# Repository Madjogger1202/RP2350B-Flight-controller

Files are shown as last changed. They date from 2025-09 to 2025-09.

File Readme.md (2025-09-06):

# RP2350B-Flight-controller  

> Ultra-compact flight controller for mini quadcopters, based on **RP2350B** MCU.  
> Board size: **30.5 × 39.8 mm**, yet includes IMU, radio module, motor drivers, and full USB power support.  
 
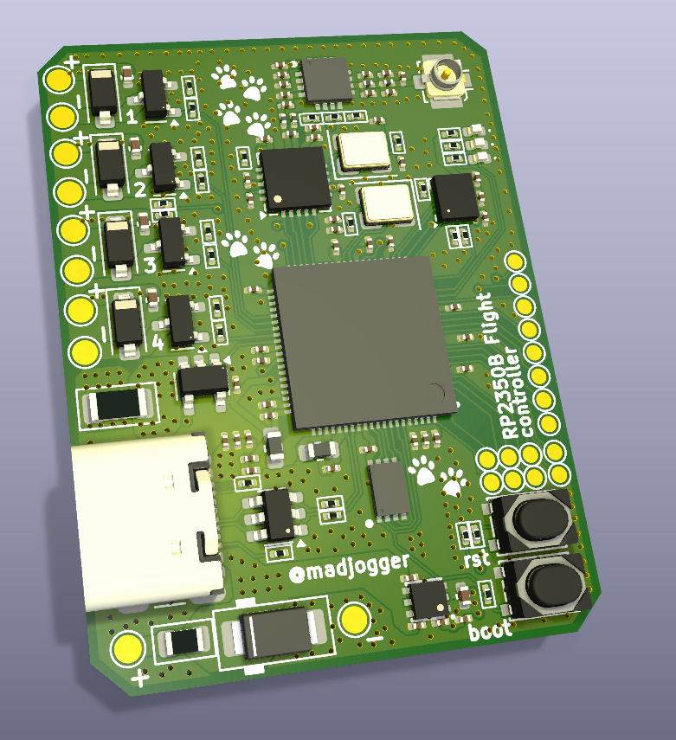
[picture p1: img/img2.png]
  

---

## Key Features  
- **MCU:** RP2350B (dual-core, PIO, USB device)  
- **IMU:** LSM6DS3 (accelerometer + gyroscope, SPI connection)  
- **Radio module:** NRF24L01 + RFX2401C PA/LNA amplifier  
- **Motors:** 4× brushed DC motors (up to 5 A per channel, short peak)  
- **USB-powered flight possible** (low-current motors, enough supply over USB)  
- **Additional expansion pins** (GPIO3–16 + SWD) for sensors, debugging, or add-ons  

---

## Pin Mapping  

### IMU (LSM6DS3) — SPI2  
| RP2350B GPIO | Signal | Notes |
|---|---|---|
| GPIO19 | SPI2_MISO | Sensor data out |
| GPIO22 | SPI2_MOSI | Sensor data in |
| GPIO23 | SPI2_SCK  | SPI clock |
| GPIO20 | IMU_INT1  | Interrupt 1 |
| GPIO21 | IMU_INT2  | Interrupt 2 |

---

### Radio Module (NRF24L01 + RFX2401C)  
| RP2350B GPIO | Signal | Notes |
|---|---|---|
| GPIO28 | SPI_MOSI | Shared SPI bus |
| GPIO36 | SPI_MISO | Shared SPI bus |
| GPIO37 | SPI_SCK  | Shared SPI bus |
| GPIO30 | NRF_CS | Chip select |
| GPIO31 | NRF_CE | Enable |
| GPIO32 | NRF_IRQ  | Interrupt |

---

### Motors  
| RP2350B GPIO | Output | Notes |
|---|---|---|
| GPIO45 | Motor_1 | Brushed motor driver |
| GPIO46 | Motor_2 | Brushed motor driver |
| GPIO47 | Motor_3 | Brushed motor driver |
| GPIO48 | Motor_4 | Brushed motor driver |
| GPIO49 | Motor_current | Current sense |
| GPIO52 | Motor_voltage | Battery/rail voltage sense |

---

### LEDs  
| RP2350B GPIO | Signal | Notes |
|---|---|---|
| GPIO17 | LED1 | Status LED |
| GPIO18 | LED2 | Status LED |

---

### Debug / Expansion  
- **SWD interface** exposed for programming/debugging  
- **GPIO3–16** free for custom extensions (I²C, UART, SPI, PWM, ADC etc.)  

---

## Power  
- Powered from **USB** or external battery  
- USB can sustain hover/low-thrust operation with small coreless motors  
- Onboard regulation for MCU, IMU, radio, and motor supply  

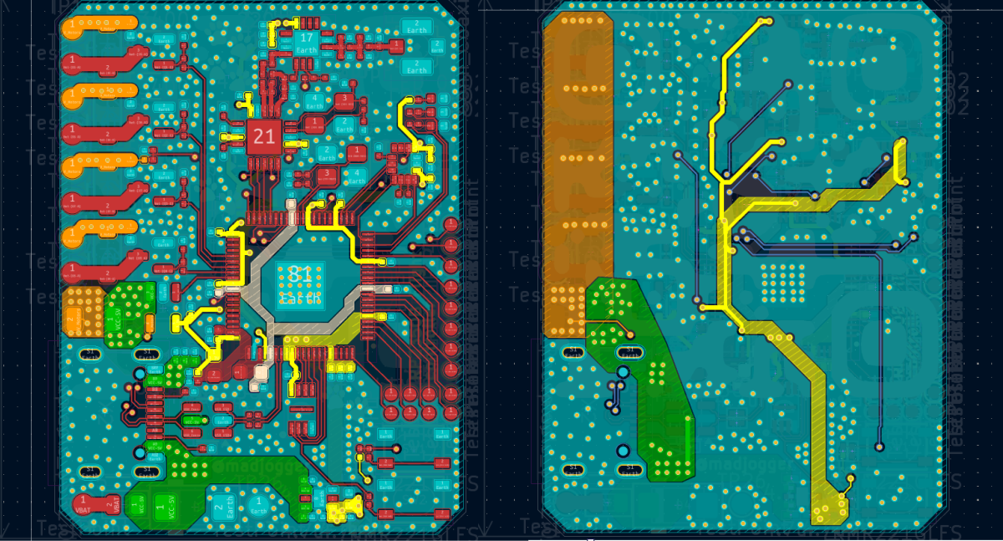
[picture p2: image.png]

---

## Use Case  
- Designed for **tiny brushed quadcopters** and robotics experiments  
- Combines **motion sensing, wireless control, and motor drivers** in one small board  
- Fits into custom drone frames without extra breakout boards  

---

## Quick Start  
1. Connect via **USB-C** for firmware flashing and testing.  
2. Flash firmware (e.g. custom flight stack on RP2350B).  
3. Connect brushed motors to outputs GPIO45–48.  
4. Pair radio link via NRF24L01 (with RFX2401C amp).  
5. Power from USB for tests, or from LiPo for flight.  

---

## Notes  
- Motor channels rated for **5 A peak per motor** (coreless brushed).  
- Ensure airflow for heat dissipation at higher loads.  
- Expansion pins allow integration of GPS, barometer, or additional sensors.  

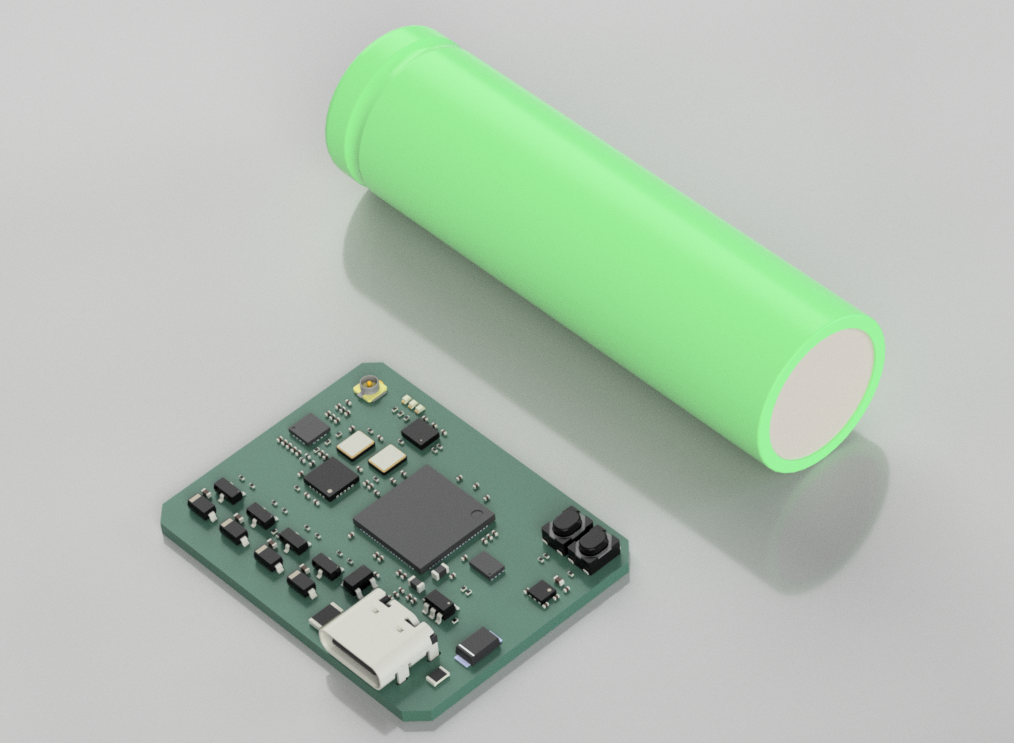
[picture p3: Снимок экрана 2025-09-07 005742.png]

---

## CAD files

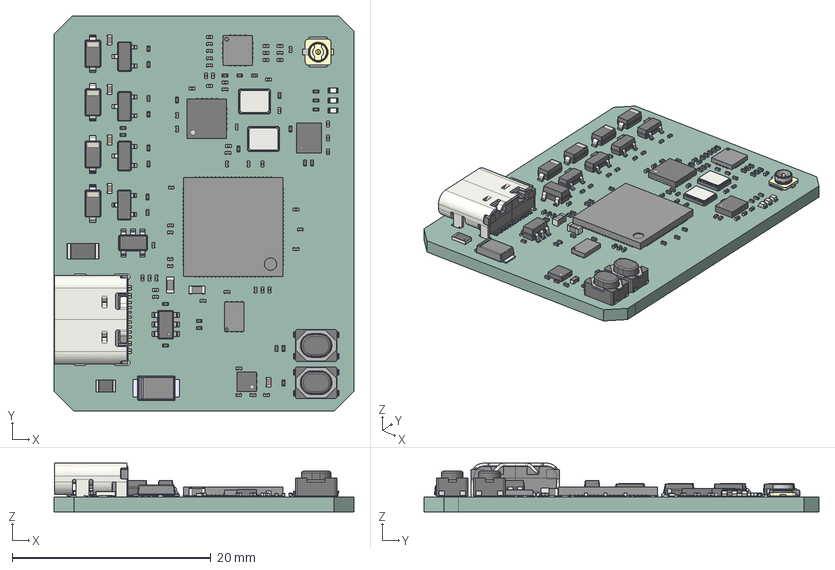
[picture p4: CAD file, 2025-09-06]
RP2350B-Flight-controller.step
30.2 x 39.8 x 4.91 mm
R_0201_0603Metric x 29
C_0201_0603Metric x 49
SS54FSH
LED_0402_1005Metric x 3
ThermalPin x 3
PinsArrayLR x 3
D_SOD-123 x 4
L_0201_0603Metric x 5
SOT-23 x 4
L_0603_1608Metric x 2
USB_C_Receptacle_GCT_USB4105-xx-A_16P_TopMnt_Horizontal
SW_SPST_PTS810 x 2
C_0402_1005Metric x 5
PinsArrayTB x 2
U.FL-R-SMT-1(80)--3DModel-STEP-1
SOT-23-5
Crystal_SMD_3225-4Pin_3.2x2.5mm x 2
QFN-20-1EP_4x4mm_P0.5mm_EP2.5x2.5mm
SOT-23-6
R_0805_2012Metric
R_1206_3216Metric
LGA-14_3x2.5mm_P0.5mm_LayoutBorder3x4y
DFN-6-1EP_2x2mm_P0.65mm_EP1x1.6mm
RP2350B-Flight-controller_PCB

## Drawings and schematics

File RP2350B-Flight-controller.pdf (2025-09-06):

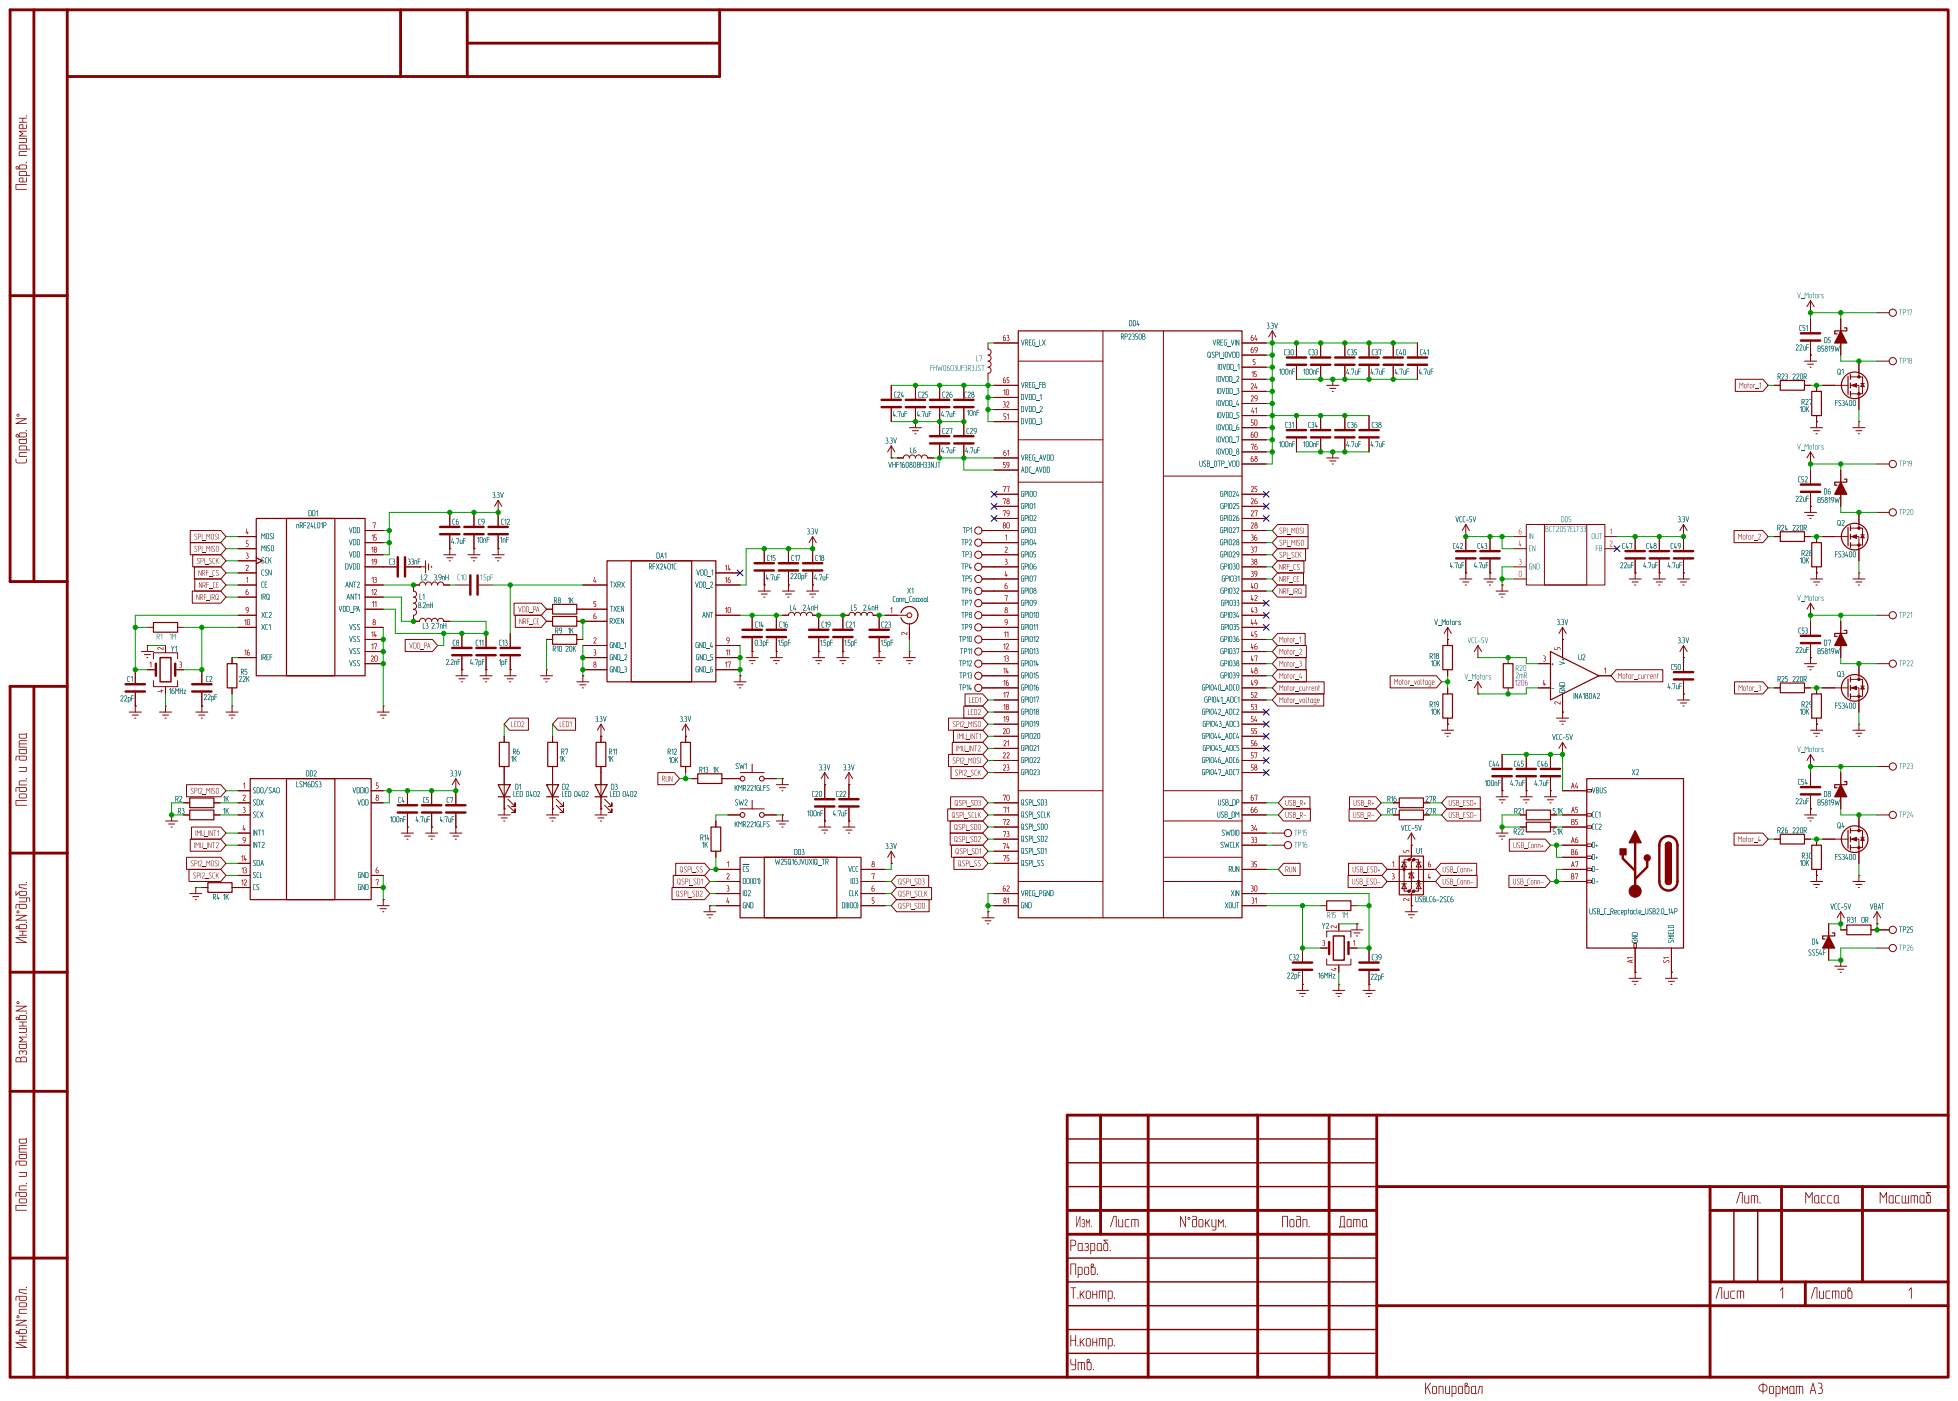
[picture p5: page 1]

þÿ@>2.
þÿ".:>=B@.

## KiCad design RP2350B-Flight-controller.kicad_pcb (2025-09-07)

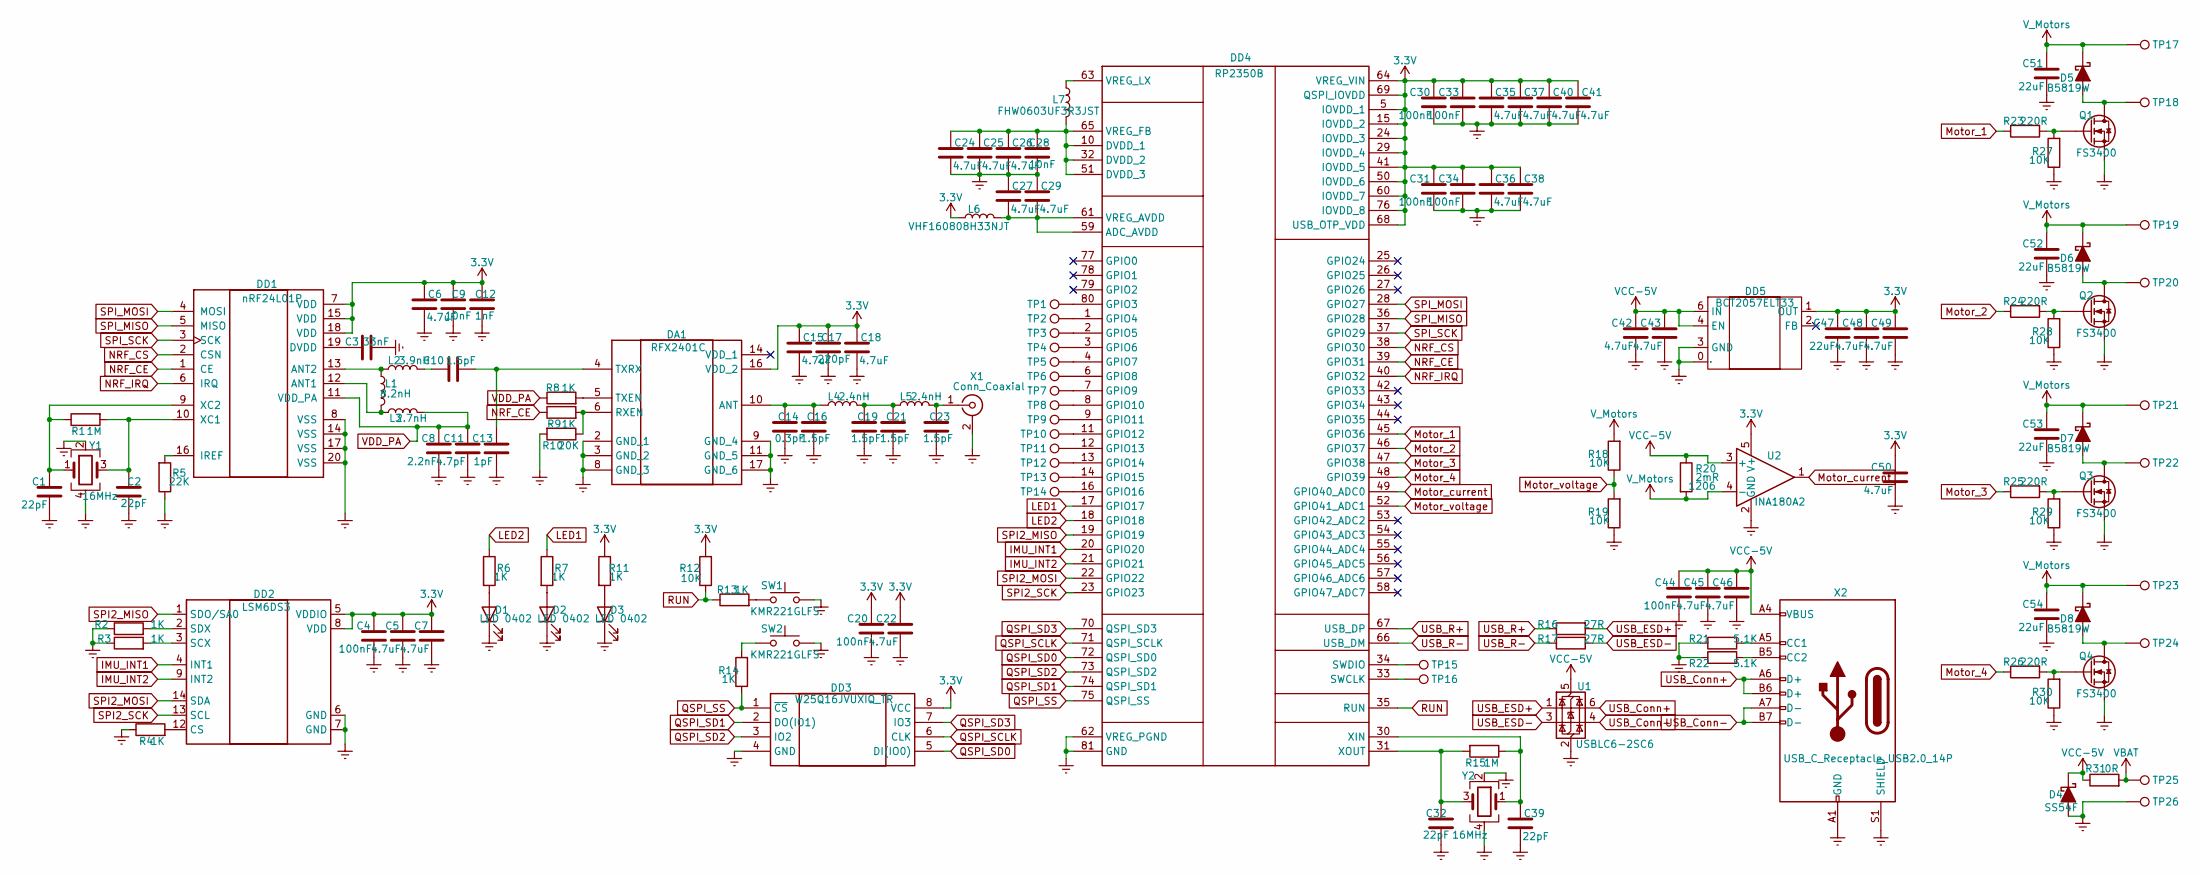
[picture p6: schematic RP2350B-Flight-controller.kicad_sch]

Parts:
C1, C2, C32, C39: 22pF; C_0201_0603Metric
C3: 33nF; C_0201_0603Metric
C4, C20, C30, C31, C33, C34, C44: 100nF; C_0201_0603Metric
C5, C6, C7, C15, C18, C22, C24, C25, C26, C27, C29, C35, C36, C37, C38, C40, C41, C42, C43, C45, C46, C48, C49, C50: 4.7uF; C_0201_0603Metric
C8: 2.2nF; C_0201_0603Metric
C9, C28: 10nF; C_0201_0603Metric
C10, C16, C19, C21, C23: 1.5pF; C_0201_0603Metric
C11: 4.7pF; C_0201_0603Metric
C12: 1nF; C_0201_0603Metric
C13: 1pF; C_0201_0603Metric
C14: 0.3pF; C_0201_0603Metric
C17: 220pF; C_0201_0603Metric
C47, C51, C52, C53, C54: 22uF; C_0402_1005Metric
D1, D2, D3: LED 0402; LED_0402_1005Metric
D4: SS54F; D_SMAFL
D5, D6, D7, D8: B5819W; D_SOD-123
DA1: RFX2401C; Manufacturer_Part_Number RFX2401C; Mouser Part Number 477-RFX2401C
DD1: nRF24L01P; QFN-20-1EP_4x4mm_P0.5mm_EP2.5x2.5mm
DD2: LSM6DS3; LGA-14_3x2.5mm_P0.5mm_LayoutBorder3x4y
DD3: W25Q16JVUXIQ_TR; W25Q16JVUXIQ; Manufacturer_Part_Number W25Q16JVUXIQ TR; Mouser Part Number 454-W25Q16JVUXIQTR
DD4: RP2350B; QFN40P1000X1000X90-81N-D; Manufacturer_Part_Number RP2350B
DD5: BCT2057ELT33; BCT2057ELTAJ; Manufacturer Part BCT2057ELTAJ-TR; LCSC Part Name 1A, 低 dropout 线性稳压器
L1: 8.2nH; L_0201_0603Metric
L2: 3.9nH; L_0201_0603Metric
L3: 2.7nH; L_0201_0603Metric
L4, L5: 2.4nH; L_0201_0603Metric
L6: VHF160808H33NJT; L_0603_1608Metric
L7: FHW0603UF3R3JST; L_0603_1608Metric
Q1, Q2, Q3, Q4: FS3400; SOT-23
R1, R15: 1M; R_0201_0603Metric
R2, R3, R4, R6, R7, R8, R9, R11, R13, R14: 1K; R_0201_0603Metric
R5: 22K; R_0201_0603Metric
R10: 20K; R_0201_0603Metric
R12, R18, R19, R27, R28, R29, R30: 10K; R_0201_0603Metric
R16, R17: 27R; R_0201_0603Metric
R20: 2mR; R_1206_3216Metric
R21, R22: 5.1K; R_0201_0603Metric
R23, R24, R25, R26: 220R; R_0201_0603Metric
R31: 0R; R_0805_2012Metric
SW1, SW2: KMR221GLFS; SW_SPST_PTS810
TP1, TP2, TP3, TP4, TP5, TP6, TP7, TP8, TP9, TP10, TP11, TP12, TP13, TP14, TP15, TP16: TestPoint; TestPoint_Pad_D1.0mm
TP17, TP18, TP19, TP20, TP21, TP22, TP23, TP24, TP25, TP26: TestPoint; TestPoint_Pad_D1.5mm
U1: USBLC6-2SC6; SOT-23-6
U2: INA180A2; SOT-23-5
X1: Conn_Coaxial; U.FL_Molex_MCRF_73412-0110_Vertical
X2: USB_C_Receptacle_USB2.0_14P; USB_C_Receptacle_GCT_USB4105-xx-A_16P_TopMnt_Horizontal
Y1, Y2: 16MHz; Crystal_SMD_3225-4Pin_3.2x2.5mm

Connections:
3.3V: C4.1, C5.1, C6.1, C7.1, C9.1, C12.1, C15.1, C17.1, C18.1, C20.1, C22.1, C30.1, C31.1, C33.1, C34.1, C35.1, C36.1, C37.1, C38.1, C40.1, C41.1, C47.1, C48.1, C49.1, C50.1, DA1.16 (VDD_2), DD1.7 (VDD), DD1.15 (VDD), DD1.18 (VDD), DD2.5 (VDDIO), DD2.8 (VDD), DD3.8 (VCC), DD4.5 (IOVDD_1), DD4.15 (IOVDD_2), DD4.24 (IOVDD_3), DD4.29 (IOVDD_4), DD4.41 (IOVDD_5), DD4.50 (IOVDD_6), DD4.60 (IOVDD_7), DD4.64 (VREG_VIN), DD4.68 (USB_OTP_VDD), DD4.69 (QSPI_IOVDD), DD4.76 (IOVDD_8), DD5.1 (OUT), L6.1, R11.1, R12.2, U2.5 (V+)
Earth: C1.2, C2.2, C3.2, C4.2, C5.2, C6.2, C7.2, C8.2, C9.2, C11.2, C12.2, C13.2, C14.2, C15.2, C16.2, C17.2, C18.2, C19.2, C20.2, C21.2, C22.2, C23.2, C24.2, C25.2, C26.2, C27.1, C28.2, C29.1, C30.2, C31.2, C32.2, C33.2, C34.2, C35.2, C36.2, C37.2, C38.2, C39.2, C40.2, C41.2, C42.2, C43.2, C44.2, C45.2, C46.2, C47.2, C48.2, C49.2, C50.2, C51.2, C52.2, C53.2, C54.2, D1.1 (K), D2.1 (K), D3.1 (K), D4.2 (A), DA1.2 (GND_1), DA1.3 (GND_2), DA1.8 (GND_3), DA1.9 (GND_4), DA1.11 (GND_5), DA1.17 (GND_6), DD1.8 (VSS), DD1.14 (VSS), DD1.17 (VSS), DD1.20 (VSS), DD1.21 (PAD), DD2.6 (GND), DD2.7 (GND), DD3.4 (GND), DD4.62 (VREG_PGND), DD4.81 (GND), DD5.0 (EP), DD5.3 (GND), Q1.2 (S), Q2.2 (S), Q3.2 (S), Q4.2 (S), R2.1, R3.1, R4.1, R5.1, R10.2, R19.1, R21.1, R22.1, R27.1, R28.1, R29.1, R30.1, SW1.1, SW2.1, TP26.1, U1.2 (GND), U2.2 (GND), X1.2 (Ext), X2.A1 (GND), X2.A12 (GND), X2.B1 (GND), X2.B12 (GND), X2.S1 (SHIELD), Y1.2, Y1.4, Y2.2, Y2.4
IMU_INT1: DD2.4 (INT1), DD4.20 (GPIO20)
IMU_INT2: DD2.9 (INT2), DD4.21 (GPIO21)
LED1: DD4.17 (GPIO17), R7.1
LED2: DD4.18 (GPIO18), R6.1
Motor_1: DD4.45 (GPIO36), R23.1
Motor_2: DD4.46 (GPIO37), R24.1
Motor_3: DD4.47 (GPIO38), R25.1
Motor_4: DD4.48 (GPIO39), R26.1
Motor_current: DD4.49 (GPIO40_ADC0), U2.1
Motor_voltage: DD4.52 (GPIO41_ADC1), R18.1, R19.2
NRF_CE: DD1.1 (CE), DD4.39 (GPIO31), R9.1
NRF_CS: DD1.2 (CSN), DD4.38 (GPIO30)
NRF_IRQ: DD1.6 (IRQ), DD4.40 (GPIO32)
unnamed: C10.1, L2.2
unnamed: C19.1, C21.1, L4.2, L5.1
unnamed: D1.2 (A), R6.2
unnamed: D2.2 (A), R7.2
unnamed: D3.2 (A), R11.2
unnamed: D5.2 (A), Q1.3 (D), TP18.1
unnamed: D6.2 (A), Q2.3 (D), TP20.1
unnamed: D7.2 (A), Q3.3 (D), TP22.1
unnamed: D8.2 (A), Q4.3 (D), TP24.1
unnamed: C14.1, C16.1, DA1.10 (ANT), L4.1
unnamed: DA1.6 (RXEN), R9.2, R10.1
unnamed: DA1.5 (TXEN), R8.2
unnamed: C10.2, C13.1, DA1.4 (TXRX)
unnamed: DD1.12 (ANT1), L1.2, L3.1
unnamed: DD1.13 (ANT2), L1.1, L2.1
unnamed: C3.1, DD1.19 (DVDD)
unnamed: DD1.16 (IREF), R5.2
unnamed: C2.1, DD1.10 (XC1), R1.2, Y1.3
unnamed: C1.1, DD1.9 (XC2), R1.1, Y1.1
unnamed: DD2.12 (CS), R4.2
unnamed: DD2.3 (SCX), R3.2
unnamed: DD2.2 (SDX), R2.2
unnamed: C27.2, C29.2, DD4.59 (ADC_AVDD), DD4.61 (VREG_AVDD), L6.2
unnamed: C24.1, C25.1, C26.1, C28.1, DD4.10 (DVDD_1), DD4.32 (DVDD_2), DD4.51 (DVDD_3), DD4.65 (VREG_FB), L7.2
unnamed: DD4.80 (GPIO3), TP1.1
unnamed: DD4.1 (GPIO4), TP2.1
unnamed: DD4.2 (GPIO5), TP3.1
unnamed: DD4.3 (GPIO6), TP4.1
unnamed: DD4.4 (GPIO7), TP5.1
unnamed: DD4.6 (GPIO8), TP6.1
unnamed: DD4.7 (GPIO9), TP7.1
unnamed: DD4.8 (GPIO10), TP8.1
unnamed: DD4.9 (GPIO11), TP9.1
unnamed: DD4.11 (GPIO12), TP10.1
unnamed: DD4.12 (GPIO13), TP11.1
unnamed: DD4.13 (GPIO14), TP12.1
unnamed: DD4.14 (GPIO15), TP13.1
unnamed: DD4.16 (GPIO16), TP14.1
unnamed: DD4.33 (SWCLK), TP16.1
unnamed: DD4.34 (SWDIO), TP15.1
unnamed: DD4.63 (VREG_LX), L7.1
unnamed: C39.1, DD4.30 (XIN), R15.1, Y2.1
unnamed: C32.1, DD4.31 (XOUT), R15.2, Y2.3
unnamed: Q1.1 (G), R23.2, R27.2
unnamed: Q2.1 (G), R24.2, R28.2
unnamed: Q3.1 (G), R25.2, R29.2
unnamed: Q4.1 (G), R26.2, R30.2
unnamed: R13.2, SW1.2
unnamed: R14.2, SW2.2
unnamed: C23.1, L5.2, X1.1 (In)
unnamed: R21.2, X2.A5 (CC1)
unnamed: R22.2, X2.B5 (CC2)
QSPI_SCLK: DD3.6 (CLK), DD4.71 (QSPI_SCLK)
QSPI_SD0: DD3.5 (DI(IO0)), DD4.72 (QSPI_SD0)
QSPI_SD1: DD3.2 (DO(IO1)), DD4.74 (QSPI_SD1)
QSPI_SD2: DD3.3 (IO2), DD4.73 (QSPI_SD2)
QSPI_SD3: DD3.7 (IO3), DD4.70 (QSPI_SD3)
QSPI_SS: DD3.1 (~CS), DD4.75 (QSPI_SS), R14.1
RUN: DD4.35 (RUN), R12.1, R13.1
SPI2_MISO: DD2.1 (SDO/SA0), DD4.19 (GPIO19)
SPI2_MOSI: DD2.14 (SDA), DD4.22 (GPIO22)
SPI2_SCK: DD2.13 (SCL), DD4.23 (GPIO23)
SPI_MISO: DD1.5 (MISO), DD4.36 (GPIO28)
SPI_MOSI: DD1.4 (MOSI), DD4.28 (GPIO27)
SPI_SCK: DD1.3 (SCK), DD4.37 (GPIO29)
USB_Conn+: U1.6 (I/O1), X2.A6 (D+), X2.B6 (D+)
USB_Conn-: U1.4 (I/O2), X2.A7 (D-), X2.B7 (D-)
USB_ESD+: R16.2, U1.1 (I/O1)
USB_ESD-: R17.2, U1.3 (I/O2)
USB_R+: DD4.67 (USB_DP), R16.1
USB_R-: DD4.66 (USB_DM), R17.1
VBAT: R31.2, TP25.1
VCC-5V: C42.1, C43.1, C44.1, C45.1, C46.1, D4.1 (K), DD5.4 (EN), DD5.6 (IN), R20.1, R31.1, U1.5 (VBUS), U2.3 (+), X2.A4 (VBUS), X2.A9 (VBUS), X2.B4 (VBUS), X2.B9 (VBUS)
VDD_PA: C8.1, C11.1, DD1.11 (VDD_PA), L3.2, R8.1
V_Motors: C51.1, C52.1, C53.1, C54.1, D5.1 (K), D6.1 (K), D7.1 (K), D8.1 (K), R18.2, R20.2, TP17.1, TP19.1, TP21.1, TP23.1, U2.4 (-)

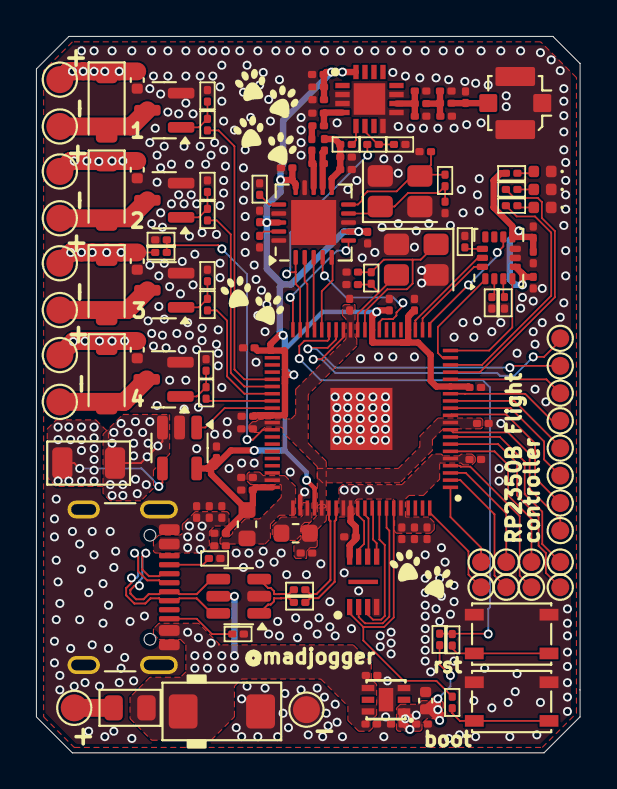
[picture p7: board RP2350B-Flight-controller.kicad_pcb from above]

Board: 2 copper layers, 30.2 x 39.8 mm, 144 parts (0 on the bottom side), 90 nets.

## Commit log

2025-09-04 started schematics
    [RP2350B-Flight-controller.kicad_pcb, RP2350B-Flight-controller.kicad_sch]
2025-09-06 schematics and component placement done
    [RP2350B-Flight-controller.kicad_pcb, RP2350B-Flight-controller.kicad_sch]
2025-09-06 rev0 ready
    [RP2350B-Flight-controller.kicad_pcb, RP2350B-Flight-controller.kicad_sch, RP2350B-Flight-controller.step]
2025-09-07 connected 21 pin of nrf24l01+ to GND
    [RP2350B-Flight-controller.kicad_pcb, RP2350B-Flight-controller.kicad_sch]
